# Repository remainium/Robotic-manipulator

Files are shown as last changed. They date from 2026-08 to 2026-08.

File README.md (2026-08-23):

# 6DOF robotic manipulator

This project consists of a robotic manipulator made up of ^ different actuators and joints, each driven by a different gearbox or type of drive, and sometimes even a different type of motor; however, the underlying use of stepper motors is maintained.
This can be driven using a master slave control system or invserse kinematics based system

# The specifications
The robot arm is capable of a 40 - 50 centimeter reach; its final end-effector speed can go up to x mm/s.
The arm has ^ actuators using stepper motors, either NEMA 17 or NEMA 23.
The manipulator has planetary gear drives and belt drives used in its actuators.
Each stepper motor has a magnetic encoder (AS5600) for position feedback

# joints, axes, and functions

- shoulder/position segment (J1-J3)

J1 - z axis - base rotation 
rotates the entire arm around the z axies

J2 - x-axis - shoulder pitch
rotates the main arm

J3 - x-axis - elbow pitch
extends and retracts the secondary segment of the arm

- wrist/psoitioning segment (J4-J6)

J4 - z-axis - wrist yaw
rotates the wrist assembly 

J5 - x-axis- wrist pitch
tilts tool 

J6 - z-axis - tool roll
spins tool around its axies

- end effector

J7 - - - end effector manipulation
this joint is an add-on claw or any tool that does some sort of manipulation

-all axes
z-x-x--z-x-z

arms for reference 

orange arm
orange robot joinmts

# Actuator specifications (oriantation/wrist)

- Joint 7
  end effector (variable)
  EF linear velocity - 
  angular velocity -

- Joint 6
  motor - nema 17
  input rpm - 100
  input torque - 3kg.cm
  gearbox - N/A

- joint 5
  motor - nema 17
  input rpm - 100
  input torque - 3kg.cm
  gearbox - single-stage planetary gear drive  5.5:1
  output torque - 15kg.cm
  output rpm - 18

- joint 4
  motor - nema 17
  input rpm - 100
  input torque - 3kg.cm
  gearbox - two-stage belt drive (3 x 4.5, 20-90 teeth, 20-60 teeth
  output torque - 40 kg · cm
  output rpm - 7.5

- joint 3
null

- joint 2
null

- joint 1
null

# pictures

Screenshot (1202)
Screenshot (1194)
Screenshot (1200)
Screenshot (1199)
Screenshot (1204)

# assembly

- joint 6
  Attach the motor to the joint 6 holster such that the input pins are exposed; screw the NEMA 17 into the inside.
  Screenshot (1207)

- joint 5
  In this joint, start by first attaching the motor mount to the NEMA 17 such that the curved shape points upward
  After that, glue nuts to the cutouts and screw on the ring section
  Then press-fit a 6809 bearing into position and fit the planet gear alinger in the middle of the bearing
  Put the sun gear on the NEMA 17 according to the D-shaped shaft and use 608 bearings and sun gears to attach to the alinger
  Glue some nuts to the alignment part, bolt the output shaft on, and attach a 6809 bearing to its exterior. After gluing the nuts onto     the top of the ring gear, bolt the cover on. You can now also glue nuts onto the output and connect the sixth joint
  Screenshot (1208)

- joint 4
  For this section, you may first bolt the NEMA 17 mount on, and then glue nuts to it, insert a 608 ball bearing into the slot, and slide down the appropriate shaft and fit it flush to the bearing. After that, mount a 90-tooth gear to it 3d printed. Use a gt2 strap belt of appropriate size, and attach a 20-tooth gear to the NEMA 17; after that, attach a 20-tooth pulley to the other end of the rod and a 60-tooth gear for the final output. Press-fit a 6809 bearing and press-fit and glue nuts to the output

# wiring diagram
WhatsApp Image 2026-08-23 at 10 36 43 PM
mains power - 36V PSU - splits to (a) motor power bus and (b) 5V logic via buck converter - ESP32 generates 6 independent step/dir signal pairs - each pair drives one TB6600 - each TB6600 drives one stepper motor, all sharing a common ground and 36V bus.

# bill of materials

| Component Name | Qty | Price (Per Unit) | Source / Link |
| :--- | :---: | :---: | :--- |
| **NEMA 23 Stepper Motor** | 2 | ~$30.30 USD *(₹2,900)* | [Robu.in](https://robu.in/product/nema-23-30-61-kg-cm-hybrid-stepper-motor/) |
| **NEMA 17 Stepper Motor** | 4 | ~$10.45 USD *(₹1,000)* | [Robu.in](https://robu.in/product/5-5-kg-cm-nema-17-stepper-motor-4-wire-bipolar-cnc-3d-printer-robotics/) |
| **Carbon Fiber Tube** <br> *(30mm Wide, 28mm ID, 1 Meter Long)* | 3 | ~$31.35 USD *(₹3,000)* | [Robu.in](https://robu.in/product/3k-roll-wrapped-carbon-fibre-tube-hollow-30mmod-28mmid-1000mml/)
| **TB6600 Stepper Driver** | 6 | ~$5.22 USD *(₹500)* | [robu.in](https://www.google.com/aclk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) |

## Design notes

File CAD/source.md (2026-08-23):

https://cad.onshape.com/documents/eeb9d3ffff9538fd74f014c1/w/aa0195100c8c43c07f09bd35/e/e548a9b86353472042d2a9de

https://cad.onshape.com/documents/a9422e186d0e285dfd983f7d/w/3eadc27ca956fa48a660c320/e/ec2ef2368b34795044b540d1

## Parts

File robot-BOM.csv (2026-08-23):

Component Name | Qty | Price (Per Unit) | Source / Link
**NEMA 23 Stepper Motor** | 2 | ~$30.30 USD *(??2,900)* | Robu.in
**NEMA 17 Stepper Motor** | 4 | ~$10.45 USD *(??1,000)* | Robu.in
**Carbon Fiber Tube** <br> *(30mm Wide, 28mm ID, 1 Meter Long)* | 3 | ~$31.35 USD *(??3,000)* | Robu.in
**TB6600 Stepper Driver** | 6 | ~$5.22 USD *(??500)* | robu.in

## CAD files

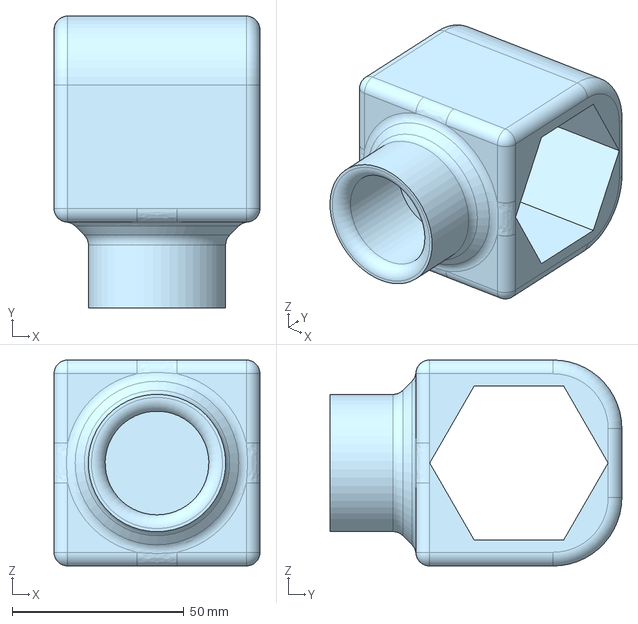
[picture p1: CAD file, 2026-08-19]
CAD/joint 4/cf holder.step
60.0 x 85.0 x 60.0 mm

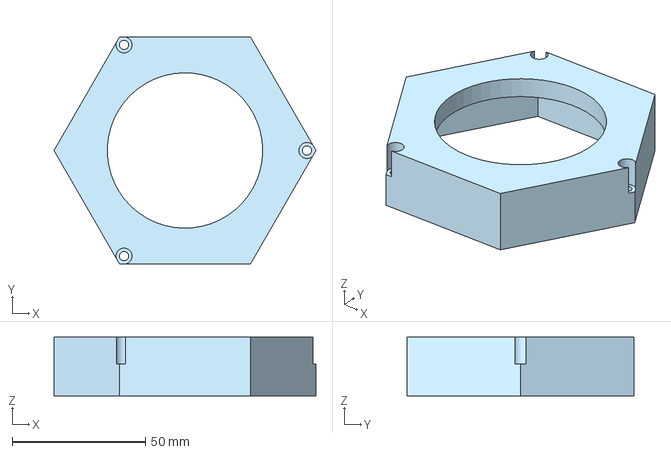
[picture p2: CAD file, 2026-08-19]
CAD/joint 5.step/gearbox cover.step
98.1 x 85.0 x 22.0 mm

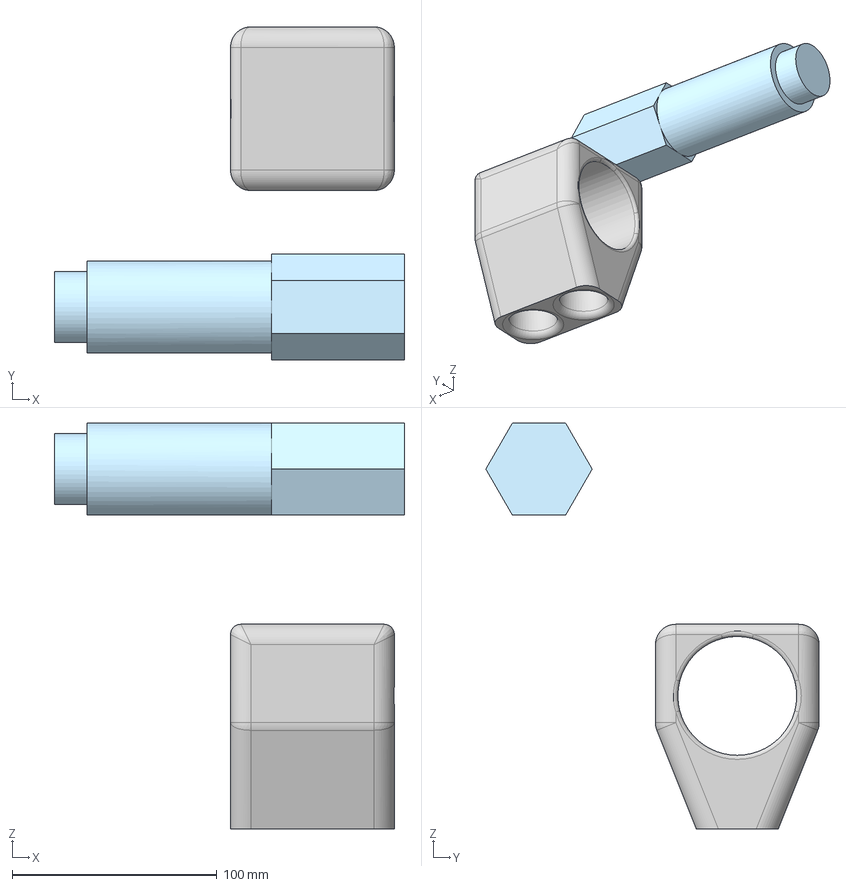
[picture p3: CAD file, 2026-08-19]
CAD/joint 4/linkage.step
171.0 x 162.8 x 198.3 mm

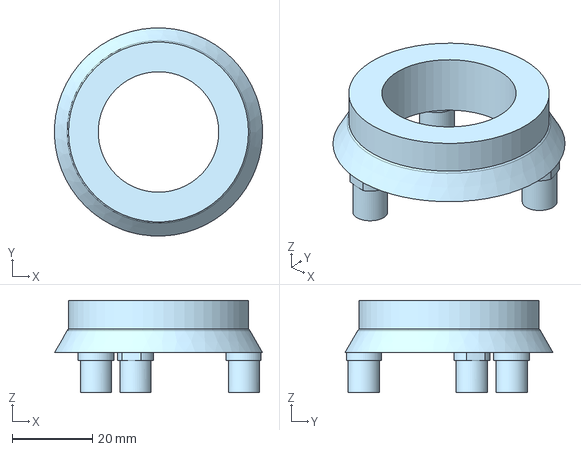
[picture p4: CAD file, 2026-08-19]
CAD/joint 5.step/planet gear alignment.step
51.8 x 51.8 x 23.0 mm

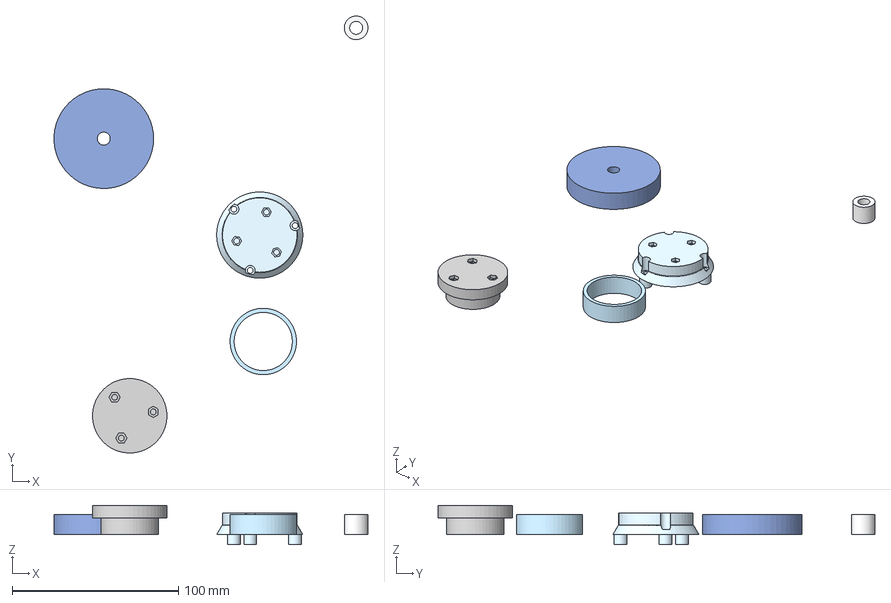
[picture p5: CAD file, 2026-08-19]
CAD/joint 4/pullys.step
188.9 x 262.9 x 23.5 mm

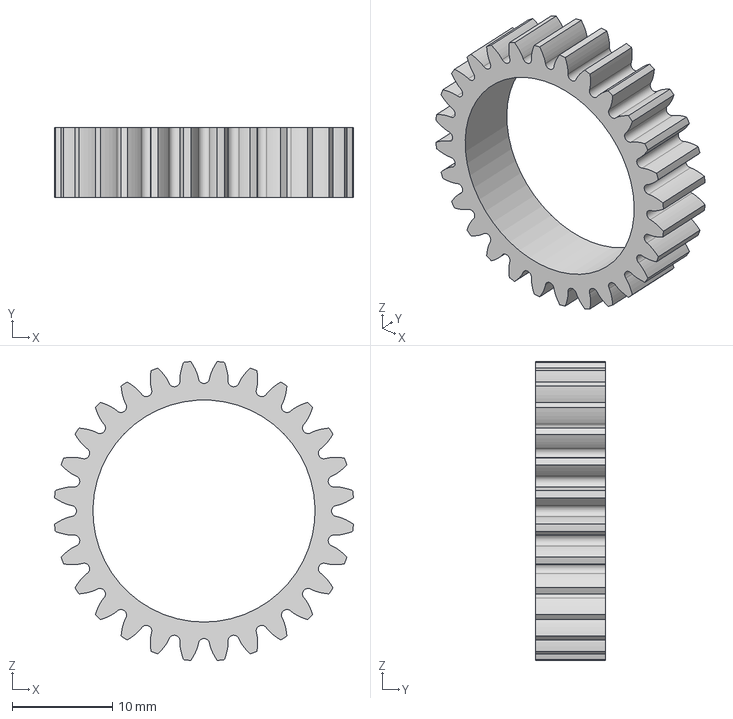
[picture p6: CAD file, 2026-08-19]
CAD/joint 5.step/planet gear.step
29.9 x 7.00 x 29.9 mm

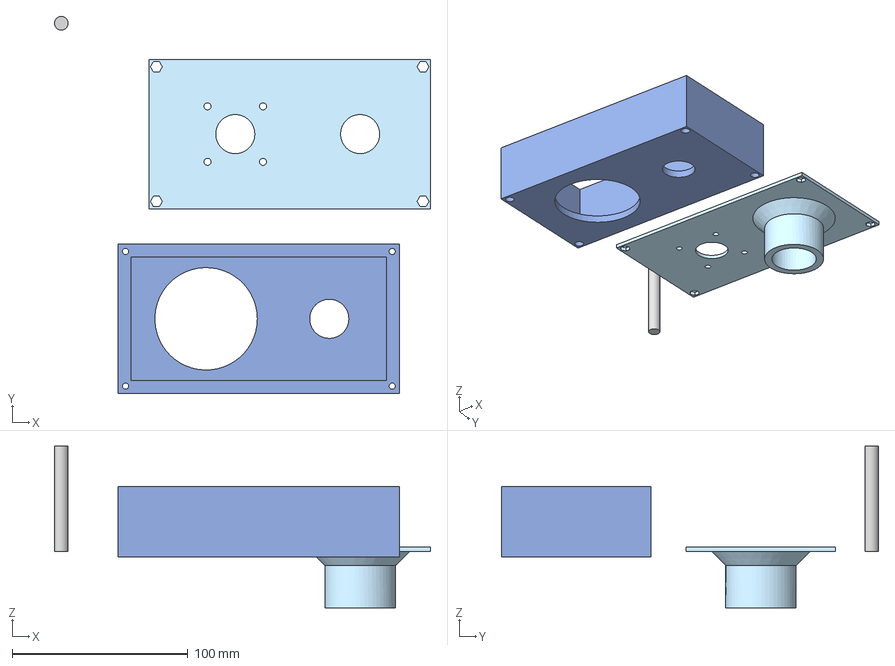
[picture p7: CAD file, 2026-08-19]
CAD/joint 4/stepper bracket.step
213.7 x 214.3 x 92.0 mm

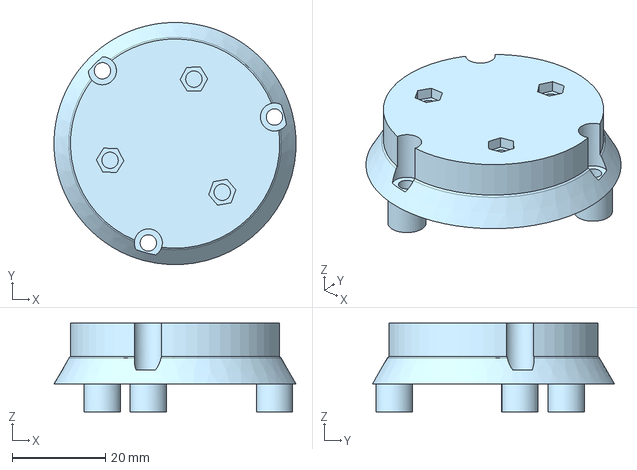
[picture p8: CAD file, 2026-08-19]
CAD/joint 5.step/output.step
51.8 x 51.8 x 19.0 mm

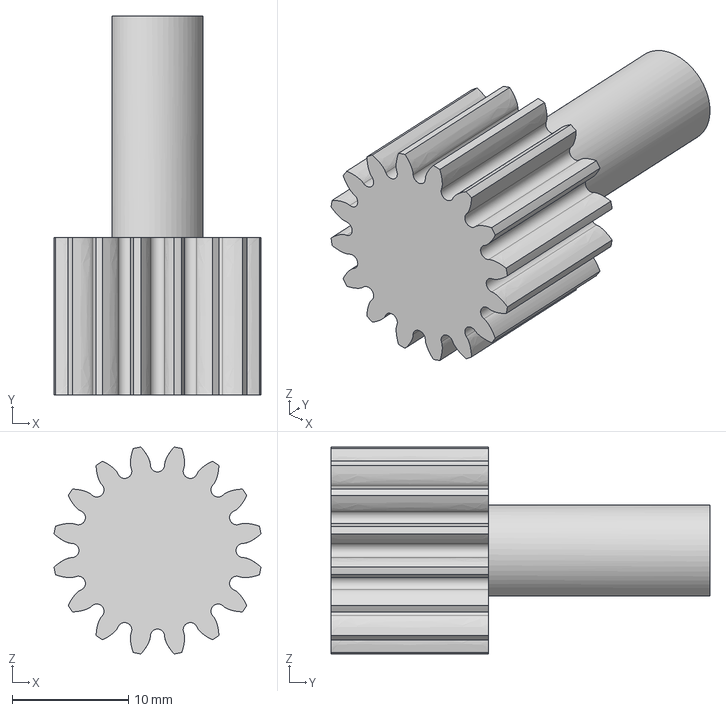
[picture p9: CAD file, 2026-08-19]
CAD/joint 5.step/sun gear.step
17.8 x 32.5 x 17.8 mm

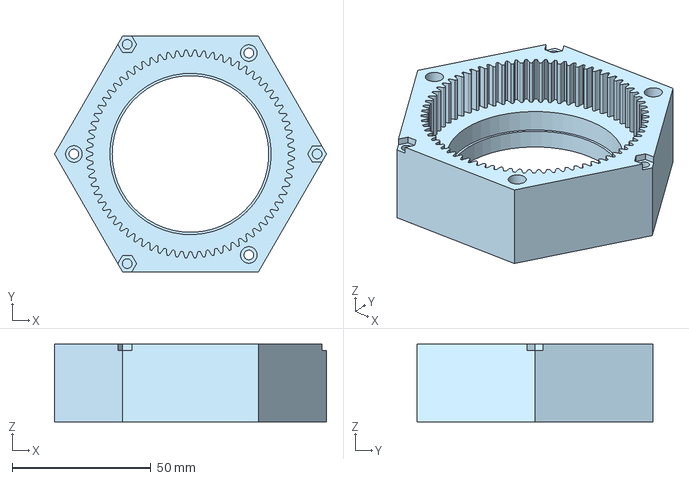
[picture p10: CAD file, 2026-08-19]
CAD/joint 5.step/ring gear.step
98.1 x 85.0 x 28.0 mm

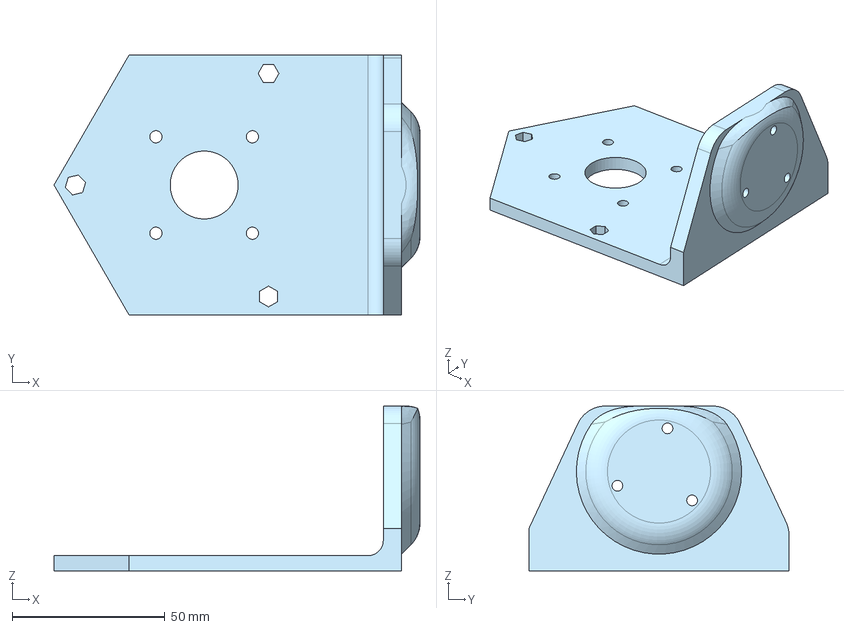
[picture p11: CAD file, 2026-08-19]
CAD/joint 5.step/nema17 bracket.step
119.6 x 85.0 x 53.9 mm

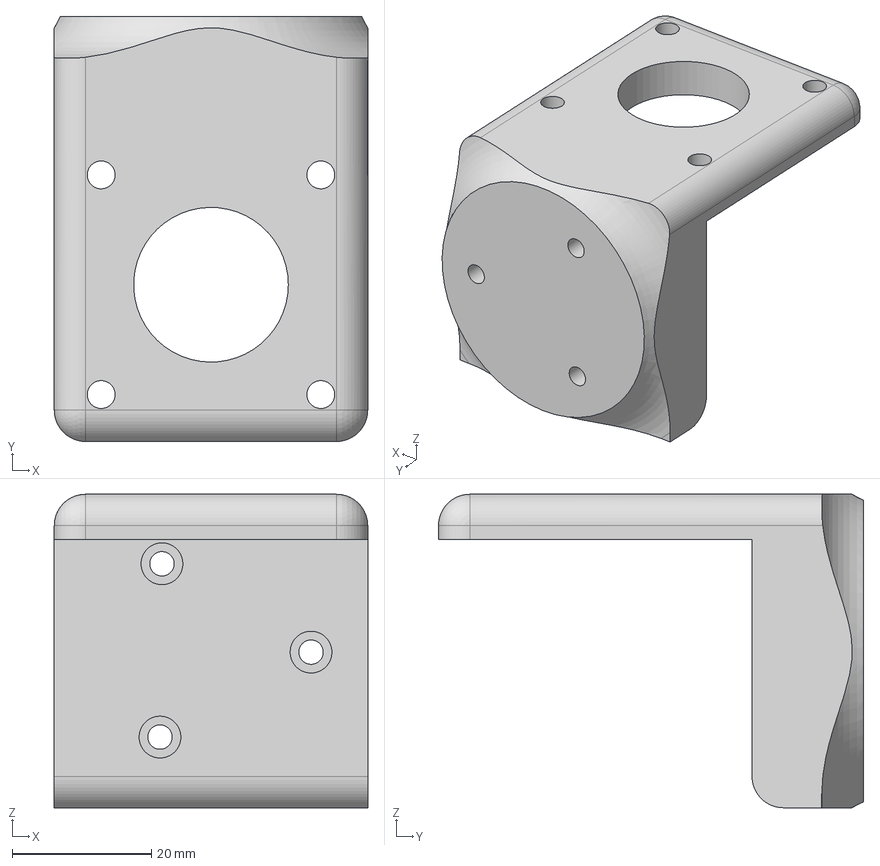
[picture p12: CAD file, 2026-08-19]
CAD/joint 5.step/J6 holster.step
45.0 x 61.0 x 45.0 mm

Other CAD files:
CAD/joint 4 stl/cf holder.stl
CAD/joint 4 stl/linkage.stl
CAD/joint 4 stl/pullys.stl
CAD/joint 4 stl/stepper bracket.stl
CAD/joint 5/J6 holster.stl
CAD/joint 5/gearbox cover.stl
CAD/joint 5/output.stl
CAD/joint 5/planet gear alignment.stl
CAD/joint 5/planet gear.stl
CAD/joint 5/ring gear.stl
CAD/joint 5/sun gear.stl

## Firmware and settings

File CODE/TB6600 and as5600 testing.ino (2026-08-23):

#include <Wire.h>
#include <AS5600.h>
AMS_5600 enc;
int p = 25; // pulse pin
int d = 26; // dir
int e = 27; // enable 
int steps = 1600; 
void setup() {
Serial.begin(115200);
Wire.begin();
  
pinMode(p, OUTPUT);
pinMode(d, OUTPUT);
pinMode(e, OUTPUT);
  
  digitalWrite(e, LOW);

  Serial.println("starting up...");
  delay(500);
  
  if (enc.detectMagnet() == 1) {
    Serial.println("magnet found!!!");
  } else {
    Serial.println("magnet not founa");
  }
}

void loop() {
  // GOING FORWARD
  digitalWrite(d, HIGH);
  Serial.println("spinning right");
  
  for (int x = 0; x < steps; x++) {
    digitalWrite(p, HIGH);
    delayMicroseconds(500); // make this smaller to go faster but it might stall
    digitalWrite(p, LOW);
    delayMicroseconds(500);
    
    
  if (x % 200 == 0) {
     int raw = enc.getRawAngle();
     float deg = raw * 0.08789;
     Serial.print("Angle: ");
  
    Serial.println(deg);
    }
  }
  
  delay(1500)

  // GOING BACKWARDS
  digitalWrite(d, LOW);
  Serial.println("spinning left");
  
  for (int x = 0; x < steps; x++) {
    digitalWrite(p, HIGH);
    delayMicroseconds(500);
    digitalWrite(p, LOW);
    delayMicroseconds(500);
    
  if (x % 200 == 0) {
      int raw = enc.getRawAngle();
      float deg = raw * 0.08789;
      Serial.print("Angle: ");
      Serial.println(deg);
    }
  }

delay(1500);
}
